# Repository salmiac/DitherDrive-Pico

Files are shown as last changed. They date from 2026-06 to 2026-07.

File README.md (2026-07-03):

# Proportional Valve Controller / Proportionaaliventtiilin Ohjain (RP2040)

This document contains instructions in both Finnish and English.
Tämä dokumentti sisältää ohjeet sekä suomeksi että englanniksi.

---

## 🇫🇮 Suomenkielinen dokumentaatio

### 1. Yleiskatsaus
Tämä projekti kuvaa edullisen, suljetun säätöpiirin (closed-loop) proportionaaliventtiiliohjaimen, joka on rakennettu Raspberry Pi Pico (RP2040) -mikrokontrollerin ympärille. Ohjain on suunniteltu erityisesti 24 V raskaan kaluston järjestelmiin (esim. Kawasakin SKC5P-14A -pumppuventtiilit).

**Pääominaisuudet:**
- **Virtatakaisinkytkentä (Closed-Loop):** Pitää venttiilin virran ja karan asennon vakaana kelan lämpötilavaihteluista huolimatta (PI-säätö INA219-sensorilla).
- **Laitteistotason Dither (muokattava):** Picon erittäin tarkan PWM-generaattorin avulla tuotettu matalataajuinen dither-signaali, joka estää venttiilin karan takertelun (stiction).
- **Tehokas laskentakyky:** RP2040:n dual-core ARM Cortex-M0+ -arkkitehtuuri tarjoaa riittävästi tehoa reaaliaikaiseen PI-säätöön, ditherin laskentaan ja sarjaporttivianmääritykseen (debugging).
- **Häiriösuojaus:** Suunniteltu sietämään työkoneiden jännitepiikkejä (Load dump) TVS- ja Zener-suojadiodeilla.

### 2. Komponenttilistaus (BOM)

| Komponentti | Malli / Tyyppi | Käyttötarkoitus | Huomautus |
| :--- | :--- | :--- | :--- |
| **Mikrokontrolleri** | Raspberry Pi Pico (RP2040) | Äly, PWM ja PI-säätö. Sisältää USB-ohjelmoinnin ja sarjaporttidebuggauksen. | Voi käyttää myös Pico W -mallia. |
| **Virtamittaus** | INA219 (I2C-moduuli) | Mittaa kelan läpi kulkevan virran reaaliajassa. | Käyttöjännite 3.3V Picon linjasta. |
| **DC/DC-muunnin** | Traco TSR 1-2450 tai Recom R-785.0 | Laskee työkoneen 24V jännitteen häviöttömästi 5 volttiin (Picon VSYS-pinnille). | Minimissään 500mA versio. |
| **Gate Driver** | TC4420 (tai MIC4427 / TC4427) | Sovittaa Picon 3.3V GPIO-signaalin MOSFETin ohjaushilalle (Gate) riittävällä jännitteellä ja virralla. | Erittäin tärkeä MOSFETin nopealle toiminnalle. |
| **MOSFET** | IRF540N tai IRL540 | Kytkee 24V jännitettä venttiilin kelalle. | IRL540 on logic-level-malli ja aukeaa matalammalla jännitteellä. |
| **Vapaakytkintädiodi** | UF5404 tai UF5408 | Nopea diodi magneettikentän purkamiseen (Fast Flyback). | UF5408 kestää korkeampaa jännitettä (1000V). |
| **Zener-diodi** | 1N5359B (24V, 5W) | Vauhdittaa kelan purkautumista yhdessä vapaakytkintädiodin kanssa. | Nopeuttaa karan palautumista. |
| **TVS-diodi** | 1.5KE36A tai 1.5KE36CA | Tappaa 24V järjestelmän yli 36V jännitepiikit. | Suojaa koko kytkentää työkoneen kuormaiskuilta. |
| **Potentiometri** | 10 kΩ (Lineaarinen) | Käyttöliittymä tavoitevirran asettamiseen (150–700 mA). | Kytketään 3.3 V jännitteeseen. |

### 3. Raspberry Pi Pico Kytkennät (Pinout)

- **VSYS (Pin 39):** Virtalähteen 5V sisääntulo (Traco/Recom DC/DC-muuntimelta).
- **GND (Pin 38 tai mikä tahansa GND):** Yhteinen maapiste (Työkoneen runko / akun miinus).
- **3.3V OUT (Pin 36):** Syöttää 3.3 V jännitteen INA219-moduulille sekä 10 kΩ potentiometrin yläpäähän.
- **GP4 / SDA (Pin 6):** INA219-moduulin SDA-pinni.
- **GP5 / SCL (Pin 7):** INA219-moduulin SCL-pinni.
- **GP26 / ADC0 (Pin 31):** Kytketään potentiometrin liukuun (suositellaan 1 kΩ sarjavastusta ja 100 nF kondensaattoria maihin RC-suotimeksi).
- **GP15 / PWM Out (Pin 20):** Kytketään TC4420 Gate Driverin IN-pinniin.

### 4. Kytkentäkaavio (Wiring Diagram)

```mermaid
graph TD
    classDef mcu fill:#008080,stroke:#004d4d,stroke-width:2px,color:#fff;
    classDef power fill:#744210,stroke:#d69e2e,stroke-width:2px,color:#fff;
    classDef sensor fill:#22543d,stroke:#38a169,stroke-width:2px,color:#fff;
    classDef driver fill:#2c5282,stroke:#4299e1,stroke-width:2px,color:#fff;
    classDef discrete fill:#4a5568,stroke:#718096,stroke-width:1px,color:#fff;
    classDef load fill:#742a2a,stroke:#e53e3e,stroke-width:2px,color:#fff;

    subgraph Power_Supply ["Power Supply & Protection / Virtalähde & Suojaus"]
        V24["24V Power Input"]:::power
        TVS["TVS Diode 1.5KE36A"]:::discrete
        Traco["DC/DC Converter (5V Out)"]:::power
        V5["5V DC/DC Output"]:::power
        GND["System Ground (GND)"]:::power
    end

    subgraph Control_Logic ["Control Logic / Ohjauslogiikka"]
        Pico["Raspberry Pi Pico"]:::mcu
        Pot["Potentiometer 10k"]:::discrete
        RC_R["Resistor 1k"]:::discrete
        RC_C["Capacitor 100nF"]:::discrete
    end

    subgraph Sensing_Driving ["Current Sensing & Power Driver / Virtamittaus & Tehoaste"]
        INA["INA219 Current Sensor"]:::sensor
        Driver["Gate Driver TC4420"]:::driver
        MOSFET["MOSFET IRF540N"]:::discrete
    end

    subgraph Actuator ["Load / Valve Coil (Kuorma / Venttiilin Kela)"]
        Coil["Proportional Valve Coil"]:::load
        UF5404["Flyback Diode UF5404"]:::discrete
        Zener["Zener Diode 1N5359B (24V)"]:::discrete
    end

    %% Power distribution
    V24 --> TVS
    TVS --> GND
    V24 -->|"Vin (Pin 1)"| Traco
    Traco -->|"GND (Pin 2)"| GND
    Traco -->|"Vout (Pin 3)"| V5

    %% Logic power
    V5 -->|"VSYS (Pin 39)"| Pico
    V5 -->|"VDD"| Driver
    Pico -->|"3.3V OUT (Pin 36) -> VCC"| INA
    Pico -->|"3.3V OUT (Pin 36) -> VCC"| Pot

    %% Analog setpoint input
    Pot -->|"Wiper"| RC_R
    RC_R --> RC_C
    RC_C --> GND
    RC_R -->|"GP26 (ADC0 / Pin 31)"| Pico

    %% Control lines
    Pico -- "GP4 (SDA) -> SDA" --> INA
    Pico -- "GP5 (SCL) -> SCL" --> INA
    Pico -- "GP15 (PWM / Pin 20) -> IN" --> Driver

    %% Load power path
    V24 -->|"VIN+"| INA
    INA -->|"VIN-"| Coil
    Coil -->|"Drain"| MOSFET
    MOSFET -->|"Source"| GND
    Driver -->|"OUT -> Gate"| MOSFET

    %% Fast Flyback path (anti-parallel to Coil)
    Coil-.-|Node 2: Drain| UF5404
    UF5404-.-|Cathode to Cathode| Zener
    Zener-.-|Anode to Node 1: VIN-| Coil

    %% GND references
    Pico ---|"GND (Pin 38)"| GND
    Pot ---|"GND"| GND
    INA ---|"GND"| GND
    Driver ---|"GND"| GND
    MOSFET ---|"Source"| GND
```

### 5. Ohjelmointi (PlatformIO)
Projekti on määritelty PlatformIO-projektiksi (juuresta löytyy `platformio.ini`), mikä on suositeltava kehitysympäristö. Pico on helppo ohjelmoida USB-liitännän kautta ilman ulkoisia ohjelmointilaitteita.

1. Avaa projektikansio VS Codessa, jossa on PlatformIO-laajennus.
2. PlatformIO käyttää `platformio.ini`-tiedostoa, johon on asetettu seuraavat asetukset Picolle (tämä lataa tarvittavat kirjastot automaattisesti):

```ini
[env:pico]
platform = raspberrypi
board = pico
framework = arduino
lib_deps = adafruit/Adafruit INA219 @ ^1.2.1
```

**Latausohje:**
1. Kytke micro-USB-kaapeli tietokoneeseen.
2. Jos koodia ladataan ensimmäistä kertaa, pidä Picon **BOOTSEL**-painiketta painettuna samalla kun kytket USB-johdon. Pico ilmestyy tietokoneelle massamuistilaitteena (RPI-RP2).
3. Paina PlatformIO:sta **Upload** (nuoli-kuvake). Kääntäjä luo `.uf2`-tiedoston ja siirtää sen automaattisesti Picolle, minkä jälkeen laite käynnistyy uudelleen ja ajaa koodia.
4. Jatkossa voit käyttää tavallista sarjaportti-uploadia suoraan PlatformIO:sta ilman BOOTSEL-painikkeen painamista.

*(Vaihtoehtoisesti koodin voi myös kääntää perinteisessä Arduino IDE -ympäristössä kopioimalla `src/main.cpp`:n sisällön uuteen luonnokseen ja asentamalla "Adafruit INA219" -kirjaston sekä "Raspberry Pi Pico" -tuen Board Managerin kautta).*

---

## 🇬🇧 English Documentation

### 1. Overview
This project details a low-cost, closed-loop proportional valve controller built around a Raspberry Pi Pico (RP2040) microcontroller. The controller is specifically designed for 24V heavy machinery systems (e.g., Kawasaki SKC5P-14A pump valves).

**Key Features:**
- **Closed-Loop Current Control:** Maintains stable coil current and spool position regardless of coil temperature variations via a PI controller reading from an INA219 current sensor.
- **Hardware Dither (Configurable):** Utilizes the RP2040's highly flexible PWM block to generate low-frequency dither PWM, preventing spool stiction.
- **High Computational Power:** The dual-core ARM Cortex-M0+ architecture provides plenty of processing overhead for real-time PI loops, dither math, and detailed serial debugging logs.
- **Transient Protection:** Designed with TVS and Zener diodes to withstand harsh 24V load dumps commonly found in heavy machinery.

### 2. Bill of Materials (BOM)

| Component | Model / Type | Purpose | Notes |
| :--- | :--- | :--- | :--- |
| **Microcontroller** | Raspberry Pi Pico (RP2040) | Core logic, PWM, and PI control. Handles USB bootloader and serial logging. | Pico W (Wi-Fi/BT) can also be used. |
| **Current Sensor** | INA219 (I2C Module) | Reads the actual current passing through the valve coil in real time. | Powered by the Pico's 3.3V rail. |
| **DC/DC Converter** | Traco TSR 1-2450 or Recom R-785.0 | Steps down the 24V system voltage to a clean 5V logic supply (Pico VSYS pin). | Minimum 500mA version. |
| **Gate Driver** | TC4420 (or MIC4427 / TC4427) | Rapidly drives the MOSFET gate using 3.3V signals stepped up to VDD (5V/12V). | Critical for fast switching. |
| **MOSFET** | IRF540N or IRL540 | Switches the 24V load across the valve coil. | IRL540 is logic-level and opens at lower voltages. |
| **Flyback Diode** | UF5404 or UF5408 | Ultra-fast rectifier for magnetic field collapse (Fast Flyback). | UF5408 features a higher voltage rating (1000V). |
| **Zener Diode** | 1N5359B (24V, 5W) | Accelerates coil discharge when placed in series with the UF5404/UF5408. | Speeds up spool spring return. |
| **TVS Diode** | 1.5KE36A or 1.5KE36CA | Suppresses voltage spikes exceeding 36V in the 24V line. | Protects the circuit from load dumps. |
| **Potentiometer** | 10 kΩ (Linear) | User interface to set target current (150–700 mA). | Connected to the 3.3V rail. |

### 3. Raspberry Pi Pico Pin Configuration

- **VSYS (Pin 39):** 5V logic supply input (from Traco/Recom DC/DC converter).
- **GND (Pin 38 or any GND):** Common ground (Chassis / Battery negative).
- **3.3V OUT (Pin 36):** Supplies 3.3V power to the INA219 module and the high end of the 10 kΩ potentiometer.
- **GP4 / SDA (Pin 6):** Connected to INA219 SDA pin.
- **GP5 / SCL (Pin 7):** Connected to INA219 SCL pin.
- **GP26 / ADC0 (Pin 31):** Connected to the 10 kΩ potentiometer wiper (a 1 kΩ series resistor and 100 nF capacitor to GND is recommended as an RC filter).
- **GP15 / PWM Out (Pin 20):** Connected to the TC4420 Gate Driver IN pin.

### 4. Wiring Diagram (Kytkentäkaavio)
*(Refer to the Mermaid diagram in the Finnish section above for the full visual schematic).*

### 5. Programming (PlatformIO)
This project is configured as a PlatformIO project (featuring a `platformio.ini` in the root), which is the recommended development environment. The Pico is flashed directly via USB without external programmers.

1. Open the project folder in VS Code with the PlatformIO extension installed.
2. PlatformIO utilizes the `platformio.ini` configuration, which is set up for the Pico as follows (this will download library dependencies automatically):

```ini
[env:pico]
platform = raspberrypi
board = pico
framework = arduino
lib_deps = adafruit/Adafruit INA219 @ ^1.2.1
```

**Flashing Instructions:**
1. Connect a micro-USB cable to your PC.
2. If uploading for the first time, hold down the **BOOTSEL** button on the Pico while plugging in the USB cable. The Pico will mount as a USB storage drive (RPI-RP2).
3. Click **Upload** (arrow icon) in PlatformIO. The toolchain compiles the code to a `.uf2` file and writes it to the Pico. The board resets and starts executing the code immediately.
4. For subsequent uploads, you can use the standard USB serial upload from PlatformIO without holding down the BOOTSEL button.

*(Alternatively, the code can be built in the traditional Arduino IDE by copying the contents of `src/main.cpp` into a new sketch, and installing the "Adafruit INA219" library and "Raspberry Pi Pico" board support via the Board Manager).*

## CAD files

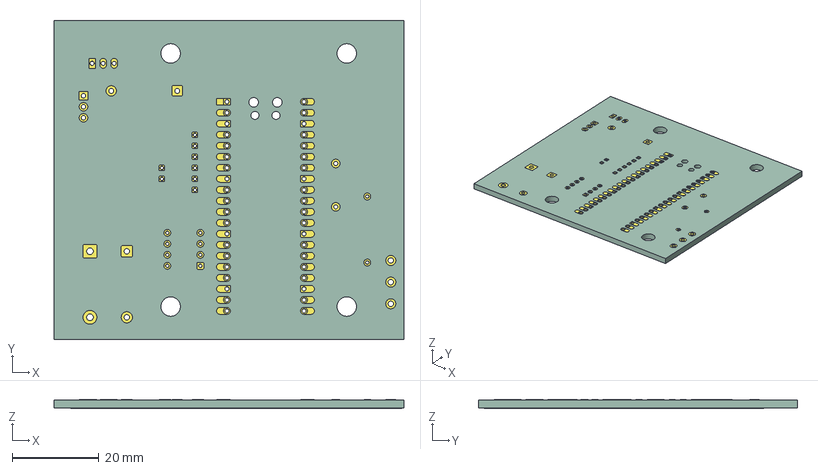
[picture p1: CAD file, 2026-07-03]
pcb/piirilevy.step
80.8 x 73.7 x 2.03 mm
DitherDrive-Tiny_copper
DitherDrive-Tiny_pad
DitherDrive-Tiny_PCB

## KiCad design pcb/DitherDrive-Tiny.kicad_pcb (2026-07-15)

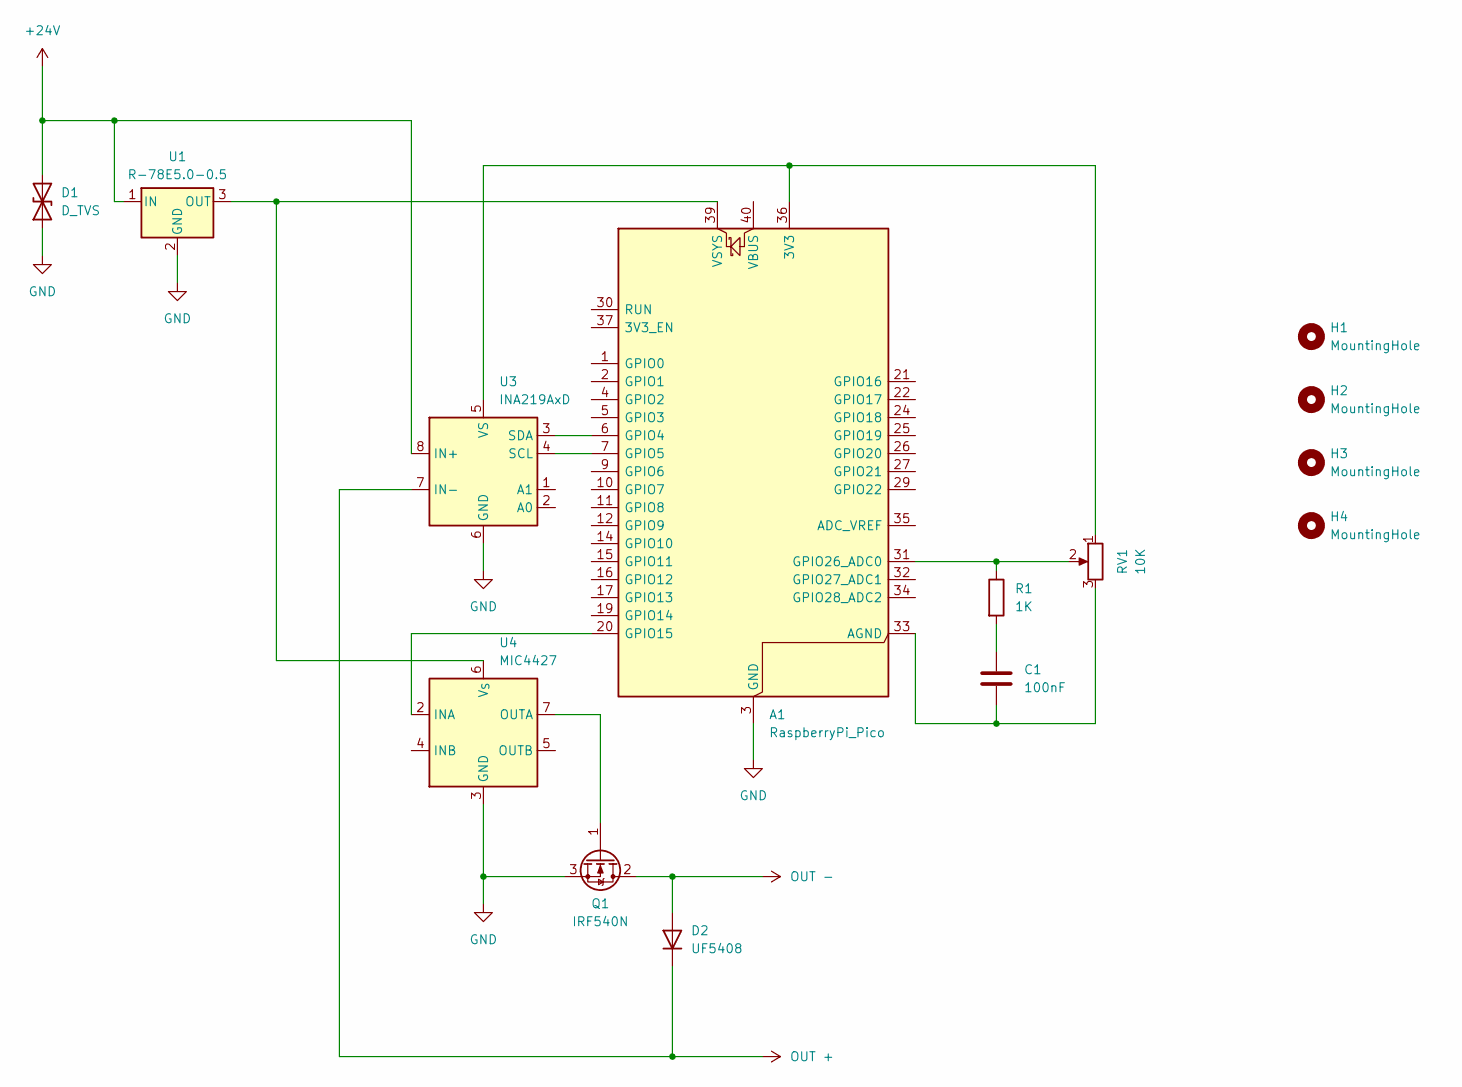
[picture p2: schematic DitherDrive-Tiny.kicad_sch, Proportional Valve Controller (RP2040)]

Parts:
A1: RaspberryPi_Pico; RaspberryPi_Pico_Common_Unspecified
C1: 100nF; C_Disc_D12.5mm_W5.0mm_P10.00mm
D1: D_TVS; D_DO-15_P15.24mm_Horizontal
D2: UF5408; D_DO-201AD_P15.24mm_Horizontal
H1, H2, H3, H4: MountingHole; MountingHole_4.5mm
Q1: IRF540N; TO-220-3_Vertical
R1: 1K; R_Axial_DIN0309_L9.0mm_D3.2mm_P15.24mm_Horizontal
RV1: 10K; Potentiometer_Piher_PC-16_Single_Horizontal
U1: R-78E5.0-0.5; Converter_DCDC_RECOM_R-78E-0.5_THT
U3: INA219AxD; INA219
U4: MIC4427; DIP-8_W7.62mm

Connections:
+24V: D1.2 (A2), U1.1 (IN), U3.8 (IN+)
GND: A1.3 (GND), A1.8 (GND), A1.13 (GND), A1.18 (GND), A1.23 (GND), A1.28 (GND), A1.38 (GND), D1.1 (A1), Q1.3 (S), U1.2 (GND), U3.6 (GND), U4.3 (GND)
unnamed: A1.36 (3V3), RV1.1, U3.5 (VS)
unnamed: A1.33 (AGND), C1.2, RV1.3
unnamed: A1.6 (GPIO4), U3.3 (SDA)
unnamed: A1.7 (GPIO5), U3.4 (SCL)
unnamed: A1.20 (GPIO15), U4.2 (INA)
unnamed: A1.31 (GPIO26_ADC0), R1.1, RV1.2
unnamed: A1.39 (VSYS), U1.3 (OUT), U4.6 (V_{S})
unnamed: C1.1, R1.2
unnamed: Q1.1 (G), U4.7 (OUTA)
OUT +: D2.1 (K), U3.7 (IN-)
OUT -: D2.2 (A), Q1.2 (D)

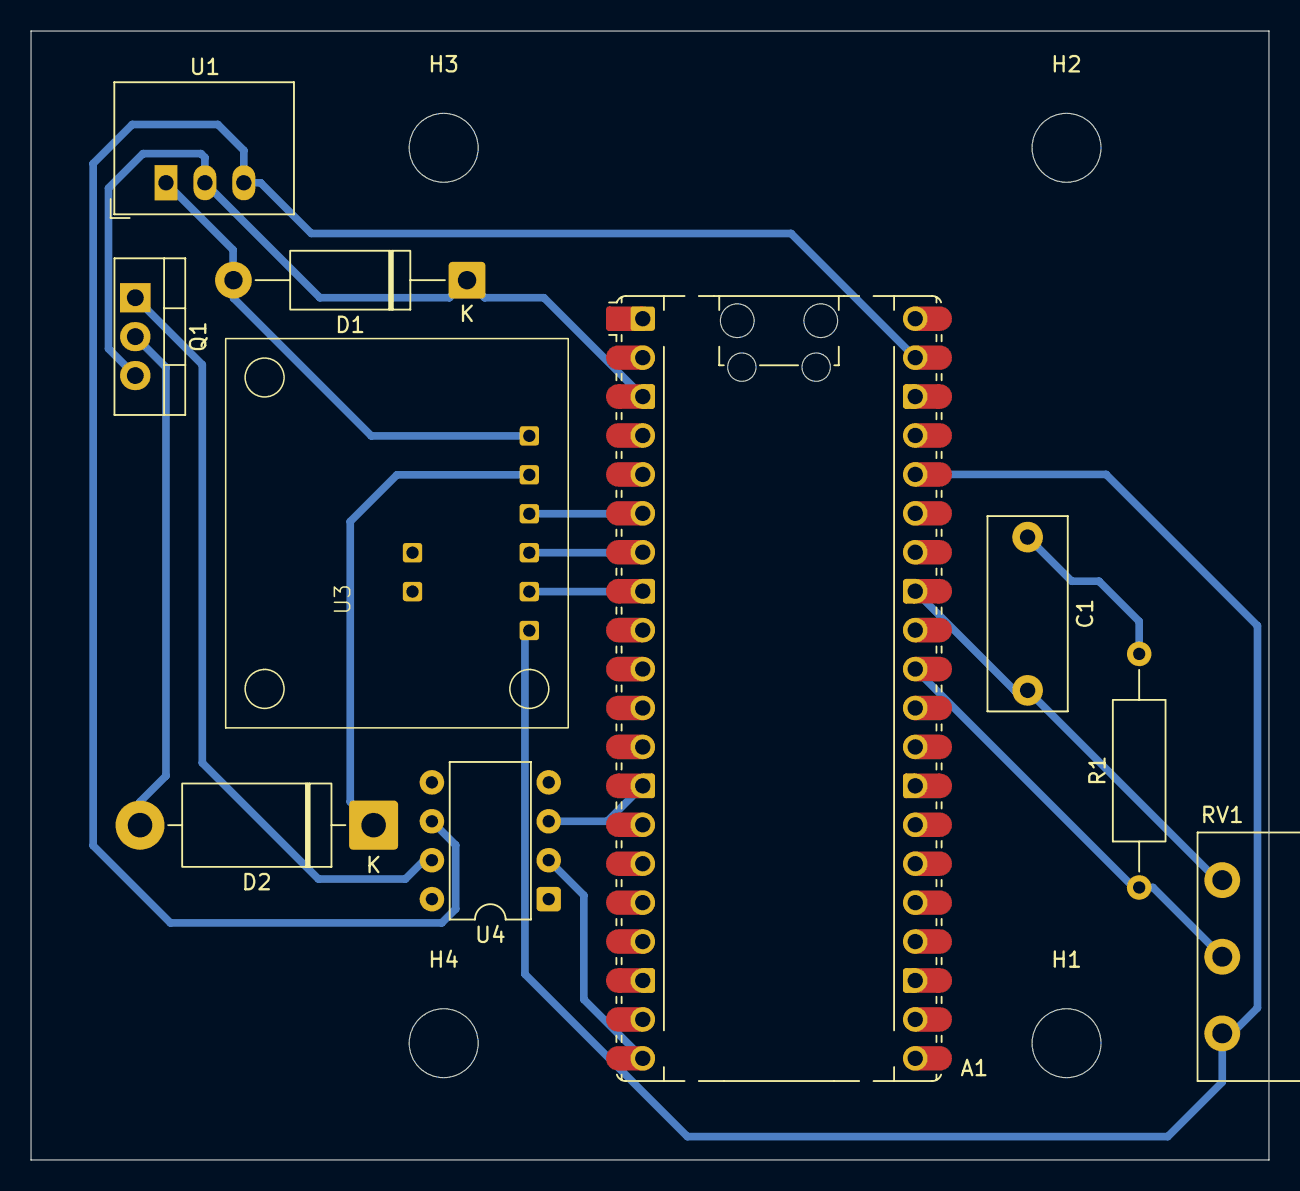
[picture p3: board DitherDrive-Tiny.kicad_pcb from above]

Board: 2 copper layers, 80.8 x 73.7 mm, 14 parts (0 on the bottom side), 13 nets.

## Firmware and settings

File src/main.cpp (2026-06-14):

#include <Arduino.h>
#include <Wire.h>
#include <Adafruit_INA219.h>
#include "hardware/pwm.h"     // Native RP2040 PWM SDK API for core compatibility

// --- PIN DEFINITIONS ---
const int PIN_POT = 26;       // GP26 (ADC0) for setting target current
const int PIN_PWM = 15;       // GP15 for MOSFET gate driver PWM

// --- CONSTANTS & CONFIGURATION ---
const float TARGET_MIN_MA = 150.0;
const float TARGET_MAX_MA = 700.0;
const float SHUTOFF_THRESHOLD_MA = 160.0; // Under this, coil is shut down completely

// PI Controller gains (can be calibrated as needed)
const float KP = 2.5f;
const float KI = 15.0f;       // Integrated over time, KI * error * dt

// PWM configuration
const uint32_t PWM_FREQ_HZ = 20000;   // 20 kHz carrier (inaudible)
const uint32_t MAX_PWM = 4095;        // 12-bit PWM resolution (0 - 4095)

// Dither configuration (122 Hz)
const uint32_t DITHER_FREQ_HZ = 122;
const uint32_t DITHER_PERIOD_US = 1000000 / DITHER_FREQ_HZ; // ~8196 us
const uint32_t DITHER_HALF_PERIOD_US = DITHER_PERIOD_US / 2; // ~4098 us
const int32_t DITHER_AMPLITUDE_PWM = 205; // ~5% of MAX_PWM (can adjust to vary physical dither amplitude)

// Loop timing
const unsigned long LOOP_INTERVAL_MS = 10; // 100 Hz loop rate (dt = 0.01s)

// Protection thresholds
const float OVERCURRENT_LIMIT_MA = 1200.0;
const float OPEN_LOAD_DUTY_THRESHOLD = 0.85f * MAX_PWM; // 85% duty cycle
const float OPEN_LOAD_CURRENT_THRESHOLD_MA = 30.0;
const unsigned long OPEN_LOAD_DELAY_MS = 2000;          // 2 seconds before trip

// Potentiometer filter alpha (EMA)
const float POT_FILTER_ALPHA = 0.1f;

// --- GLOBAL VARIABLES ---
Adafruit_INA219 ina219;

float filteredAdc = 0.0f;
float activeTargetCurrent = 0.0f; // Ramped target current
float iTerm = 0.0f;               // Integral term accumulator

// Dither state variables
volatile bool ditherState = false;
unsigned long lastDitherToggle = 0;

// Loop timing variable
unsigned long lastLoopTime = 0;

// Protection state variables
bool overcurrentTripped = false;
bool openLoadTripped = false;
unsigned long openLoadTimer = 0;

// Function declarations
float mapFloat(float x, float in_min, float in_max, float out_min, float out_max);
void checkProtections(float actualCurrent, uint32_t baseDuty);
void handleSerialDebug(float potTarget, float actualCurrent, uint32_t baseDuty, uint32_t finalDuty);

void setup() {
    // Start USB Serial for debugging
    Serial.begin(115200);
    
    // Configure analog read pin
    pinMode(PIN_POT, INPUT);
    
    // Configure PWM using native RP2040 hardware PWM SDK API
    gpio_set_function(PIN_PWM, GPIO_FUNC_PWM);
    uint slice_num = pwm_gpio_to_slice_num(PIN_PWM);
    
    // Set clock divider and wrap for 20 kHz carrier frequency at 12-bit resolution
    // f = 125 MHz / (clkdiv * (wrap + 1))
    // 20000 = 125000000 / (clkdiv * 4096) -> clkdiv = 6250 / 4096 = 1.5258789
    pwm_set_clkdiv(slice_num, 1.526f);
    pwm_set_wrap(slice_num, MAX_PWM);
    pwm_set_gpio_level(PIN_PWM, 0); // Start at 0% duty cycle
    pwm_set_enabled(slice_num, true);

    // Initialize I2C. Default I2C0 pins are GP4 (SDA) and GP5 (SCL) on standard RP2040.
    Wire.begin();

    Serial.println("--- Proportional Valve Controller Starting ---");

    if (!ina219.begin()) {
        Serial.println("CRITICAL ERROR: Failed to find INA219 current sensor chip!");
        while (1) { delay(10); } // Halt if sensor not found
    }
    
    // By default, INA219 initializes to 32V / 2A range, which fits our 24V / 0.7A max load.
    Serial.println("INA219 Current Sensor Initialized successfully.");
    
    // Seed the pot filter with initial reading
    filteredAdc = analogRead(PIN_POT);
    lastLoopTime = millis();
    lastDitherToggle = micros();
}

void loop() {
    unsigned long currentMillis = millis();

    // 1. DITHER TOGGLE BLOCK (Independent of main 10ms loop for timing accuracy)
    unsigned long currentMicros = micros();
    if (currentMicros - lastDitherToggle >= DITHER_HALF_PERIOD_US) {
        ditherState = !ditherState;
        lastDitherToggle = currentMicros;
    }

    // 2. MAIN CONTROL LOOP (Runs at 100 Hz / 10ms)
    if (currentMillis - lastLoopTime >= LOOP_INTERVAL_MS) {
        lastLoopTime = currentMillis;

        // Read sensor current
        float actualCurrent = 0.0f;
        if (!overcurrentTripped && !openLoadTripped) {
            actualCurrent = abs(ina219.getCurrent_mA());
        }

        // Read and filter target setpoint from potentiometer
        float rawAdc = analogRead(PIN_POT);
        filteredAdc = (1.0f - POT_FILTER_ALPHA) * filteredAdc + POT_FILTER_ALPHA * rawAdc;

        // Map filtered ADC to target current range
        float potTarget = mapFloat(filteredAdc, 0.0f, 4095.0f, TARGET_MIN_MA, TARGET_MAX_MA);

        // Reset trips if potentiometer is turned to the absolute minimum
        if (potTarget < SHUTOFF_THRESHOLD_MA && (overcurrentTripped || openLoadTripped)) {
            overcurrentTripped = false;
            openLoadTripped = false;
            iTerm = 0.0f;
            Serial.println("Protection trips reset via low setpoint command.");
        }

        // Handle valve shutoff below threshold
        float targetCurrent = 0.0f;
        if (potTarget >= SHUTOFF_THRESHOLD_MA && !overcurrentTripped && !openLoadTripped) {
            targetCurrent = potTarget;
        }

        // Soft Start / Ramping: limit target current rate of change
        const float rampRate = 5.0f; // mA limit per 10ms (500 mA/second ramp rate)
        if (activeTargetCurrent < targetCurrent) {
            activeTargetCurrent = min(activeTargetCurrent + rampRate, targetCurrent);
        } else if (activeTargetCurrent > targetCurrent) {
            activeTargetCurrent = max(activeTargetCurrent - rampRate, targetCurrent);
        }

        // PI Controller calculation
        uint32_t baseDuty = 0;
        if (activeTargetCurrent > 0.0f) {
            float error = activeTargetCurrent - actualCurrent;
            float pTerm = KP * error;
            iTerm += KI * error * 0.01f; // dt = 10ms = 0.01s

            // Anti-windup clamping
            iTerm = constrain(iTerm, 0.0f, (float)MAX_PWM);

            float output = pTerm + iTerm;
            baseDuty = constrain((int32_t)output, 0, (int32_t)MAX_PWM);
        } else {
            iTerm = 0.0f; // Reset integrator when shut off
            baseDuty = 0;
        }

        // Safety checking
        checkProtections(actualCurrent, baseDuty);

        // Calculate and apply dither
        uint32_t finalDuty = 0;
        if (activeTargetCurrent > 0.0f && !overcurrentTripped && !openLoadTripped) {
            int32_t ditherOffset = ditherState ? DITHER_AMPLITUDE_PWM : -DITHER_AMPLITUDE_PWM;
            finalDuty = constrain((int32_t)baseDuty + ditherOffset, 0, (int32_t)MAX_PWM);
        } else {
            finalDuty = 0; // Disable PWM output entirely if stopped or tripped
        }

        // Write PWM level using native RP2040 SDK API
        pwm_set_gpio_level(PIN_PWM, finalDuty);

        // Debug logging to USB Serial
        handleSerialDebug(potTarget, actualCurrent, baseDuty, finalDuty);
    }
}

float mapFloat(float x, float in_min, float in_max, float out_min, float out_max) {
    return (x - in_min) * (out_max - out_min) / (in_max - in_min) + out_min;
}

void checkProtections(float actualCurrent, uint32_t baseDuty) {
    // 1. Overcurrent Protection
    if (actualCurrent > OVERCURRENT_LIMIT_MA) {
        overcurrentTripped = true;
        pwm_set_gpio_level(PIN_PWM, 0); // Shut down immediately
        Serial.print("CRITICAL ERROR: Overcurrent tripped! Measured: ");
        Serial.print(actualCurrent);
        Serial.println(" mA");
    }

    // 2. Open-Load Protection (Broken Wire / Disconnected Valve)
    if (baseDuty > OPEN_LOAD_DUTY_THRESHOLD && actualCurrent < OPEN_LOAD_CURRENT_THRESHOLD_MA) {
        if (openLoadTimer == 0) {
            openLoadTimer = millis();
        } else if (millis() - openLoadTimer >= OPEN_LOAD_DELAY_MS) {
            openLoadTripped = true;
            pwm_set_gpio_level(PIN_PWM, 0); // Shut down immediately
            Serial.println("CRITICAL ERROR: Open Load tripped! Duty cycle high but no current detected.");
        }
    } else {
        openLoadTimer = 0; // Reset open load timer if conditions aren't met
    }
}

void handleSerialDebug(float potTarget, float actualCurrent, uint32_t baseDuty, uint32_t finalDuty) {
    static unsigned long lastLogTime = 0;
    if (millis() - lastLogTime >= 200) { // Log every 200ms
        lastLogTime = millis();

        if (overcurrentTripped) {
            Serial.println("[STATUS] TRIPPED: Overcurrent. Turn potentiometer to min to reset.");
        } else if (openLoadTripped) {
            Serial.println("[STATUS] TRIPPED: Open Load (Broken wire). Turn potentiometer to min to reset.");
        } else {
            Serial.print("Target: ");
            Serial.print(potTarget, 1);
            Serial.print(" mA | Ramped: ");
            Serial.print(activeTargetCurrent, 1);
            Serial.print(" mA | Measured: ");
            Serial.print(actualCurrent, 1);
            Serial.print(" mA | PI Duty: ");
            Serial.print(mapFloat((float)baseDuty, 0, MAX_PWM, 0, 100), 1);
            Serial.print("% | Dither: ");
            Serial.print(ditherState ? "+" : "-");
            Serial.print(" | Final: ");
            Serial.print(mapFloat((float)finalDuty, 0, MAX_PWM, 0, 100), 1);
            Serial.println("%");
        }
    }
}
